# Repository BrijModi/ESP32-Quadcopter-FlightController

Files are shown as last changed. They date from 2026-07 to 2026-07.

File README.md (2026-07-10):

# ESP32-Quadcopter-FlightController

Open-source ESP32-based flight controller for quadcopters, featuring sensor fusion, nested PID control, motor mixing, real-time Wi-Fi PID tuning, and a custom KiCad PCB with support for GPS and FPV modules.

---

## 📘 Introduction
This project is a fully custom **ESP32-based quadcopter flight controller**, built from scratch to provide complete hardware and firmware flexibility.  
Unlike commercial closed-source flight controllers, this system allows direct modification of IMU handling, PID algorithms, motor mixing, and communication layers—making it ideal for learning, research, and UAV experimentation.

The controller runs an **83 Hz control loop**, uses a **complementary filter** for real-time roll/pitch estimation, and stabilizes the quadcopter using **nested PID loops** (Angle + Rate).  
A built-in **Wi-Fi interface** enables on-the-fly PID tuning and telemetry, eliminating the need to reflash firmware between adjustments.

This repository includes the complete firmware, custom KiCad PCB design, calibration and testing utilities, project media, and a comprehensive technical report documenting the system design and implementation.

---

## ⭐ Highlights
- Custom ESP32-based flight controller firmware  
- Complementary filter for attitude estimation  
- Dual-loop PID control for roll, pitch, and yaw  
- Motor mixing for X-configuration quadcopters  
- Real-time Wi-Fi tuning dashboard  
- Custom two-layer PCB with expansion support  
- Stable and tested flight performance (90–95%)  
- Open-source and fully modifiable

---

## 🖼 Drone Image

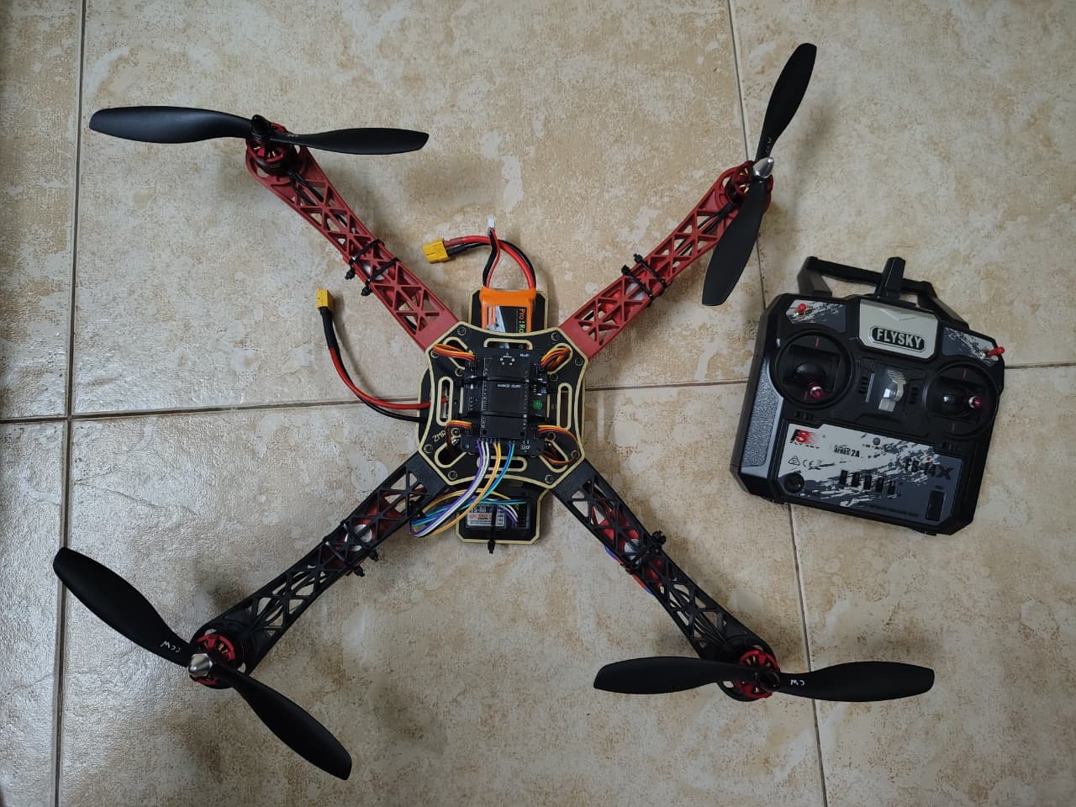
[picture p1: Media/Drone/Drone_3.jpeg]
Custom ESP32 Quadcopter


---

## 🔧 Features
- Real-time IMU data acquisition using MPU6050  
- Complementary filter–based angle estimation  
- Nested PID loops for angle and rate stabilization  
- PWM signal generation for ESCs  
- i-BUS / PWM receiver input handling  
- Wi-Fi HTTP server for dashboard + tuning  
- Support for barometer (alt-hold), GPS, and FPV modules  
- Modular code structure for easy experimentation

---

## 🛠 Hardware Used
- ESP32 DevKit V1
- MPU6050 IMU  
- RS-2212 920KV motors + 30A ESCs  
- FlySky FS-i4X receiver  
- 3S Li-Po battery  
- F450 frame  
- Custom-designed flight controller PCB

---

## 📂 Repository Contents

- `Firmware/`
  - `Main_Firmware/` – Main ESP32-based quadcopter flight controller firmware
  - `Testing_Calibration/` – Calibration, testing, and Wi-Fi PID tuning utilities
  
- `Hardware/`
  - `Drone Flight Controller/` – Complete KiCad project (schematic, PCB layout, and project files)
  - `FC Gerber.zip` – PCB manufacturing (Gerber) files
  - `PCB View.pdf` – PCB layout overview
  - `Schematic.pdf` – Flight controller circuit schematic
  
- `Media/`
  - `Drone/` – Drone assembly, flight controller, and hardware images
  - `Test Flight and Calibration/` – Flight test videos, calibration recordings, and PID response graph

- `Technical Report.pdf` – Comprehensive technical documentation covering hardware design, firmware architecture, implementation, and testing

---

## 💻 Software Requirements

- Arduino IDE 2.x
- ESP32 Arduino Core
- KiCad 9.x (for PCB design)

---

## 📚 Libraries Used

- `Wire` – I²C communication
- `ESP32Servo` – ESC PWM control
- `WiFi` – Wireless communication
- `AsyncTCP` – Asynchronous TCP networking
- `ESPAsyncWebServer` – Web-based PID tuning dashboard
- `SPIFFS` – Web dashboard file storage

---

## 🚀 Getting Started

Follow the steps below to configure and fly the quadcopter for the first time.

### 1. Hardware Setup
- Assemble the quadcopter and connect all hardware components.
- Wire the ESP32, MPU6050, ESCs, receiver, and motors according to the provided schematic.

### 2. Verify Receiver and ESCs
- Upload the firmware from `Firmware/Testing_Calibration/Receiver_PWM_Testing/` to verify proper receiver operation.
- Upload the firmware from `Firmware/Testing_Calibration/ESC_Calibration/` and calibrate all ESCs.

### 3. Calibrate the IMU
- Upload the firmware from `Firmware/Testing_Calibration/IMU_Calibration/`.
- Place the quadcopter on a level surface and perform the IMU calibration.
- Copy the generated accelerometer and gyroscope offset values into both the main flight controller firmware and the PID tuning firmware.

### 4. Tune the PID Controller
- Upload the firmware from `Firmware/Testing_Calibration/PID_Tuning_Webserver/`.
- Connect to the ESP32 Wi-Fi access point and open the PID tuning dashboard.
- Tune the roll, pitch, and yaw PID gains until stable flight performance is achieved.
- Copy the optimized PID values into the main flight controller firmware.

### 5. Upload the Main Flight Controller Firmware
- Open `Firmware/Main_Firmware/Flight_Controller_v2/Flight_Controller_v2.ino`.
- Update the firmware with the calibrated IMU offsets and tuned PID gains.
- Upload the firmware to the ESP32.

### 6. Perform Flight Testing
- Verify the motor rotation direction and propeller orientation.
- Perform an initial low-throttle hover test in a safe, open area.
- Fine-tune the PID gains as required to achieve stable and responsive flight.

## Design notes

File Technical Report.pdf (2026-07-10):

# Design and Implementation of a Custom ESP32-Based Quadcopter Flight Controller

Brij Modi

October 2025

Abstract
This report summarizes the design and implementation of a fully custom-built quadcopter with a self-developed flight controller using an ESP32 microcontroller and an MPU6050 IMU. The main goal is to develop a low-cost, modular, and customizable flight control system that allows total hardware and software flexibility, as opposed to conventional commercial controllers. The system includes real-time attitude estimation by using a complementary filter and stabilization using a dual-loop PID control architecture over roll, pitch, and yaw axes. A web-based Wi-Fi interface for wireless PID tuning without firmware reprogramming allows easy calibration. A quadcopter built using an F450 frame with A2212-1400KV motors, SimonK 30A ESCs, and an FS-i4X transmitter showed stable flights with more than 90% stability in manual flight tests. Other optional functions like altitude hold, GPS navigation support, and FPV camera are integrated into the PCB design for potential autonomous functions and broader application scenarios.

## 1 Introduction

Unmanned Aerial Vehicles (UAVs) have revolutionized various activities such as aerial mapping, surveillance applications, precision agriculture, and scientific exploration. Among the several types of UAVs, quadcopters are renowned for mechanical simplicity, vertical takeoff and landing capabilities, and high maneuverability. Because of this, they are preferred platforms not only in research but also in practical applications.

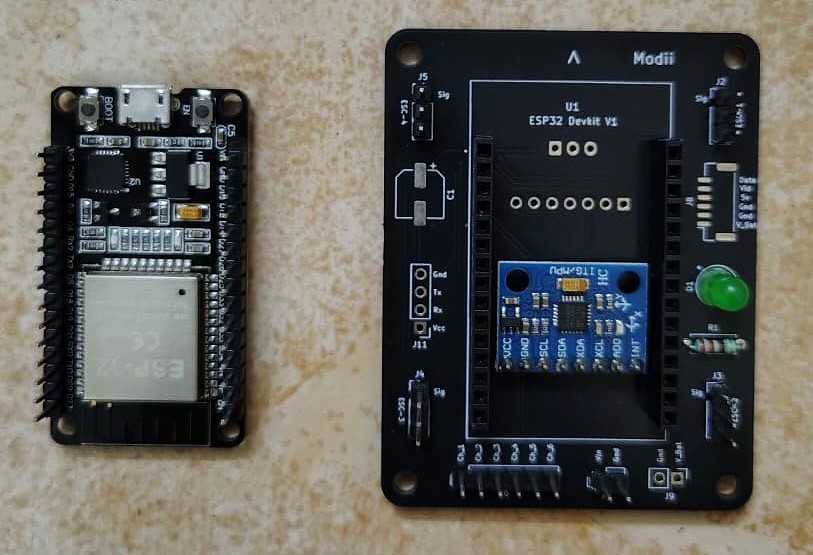
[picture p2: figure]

ESP32-based flight controller PCB.

While commercial flight controllers, such as the KK and Naze32, are very powerful and feature-rich, their closed-source firmware or limited customization usually restricts new control algorithm or sensor configuration experimentation. This limits the educational and research efforts that need deeper insight into embedded control design and firmware customization.
The following work will fill this gap by detailing the design and implementation of a completely custom ESP32-based quadcopter flight controller. It is fitted with an MPU6050 IMU for real-time attitude sensing, a dual-loop PID control structure for precise stabilization, and a web-based interface for wireless tuning. While stable flights can be realized in this project, it focuses more on the end-toend development from circuit design, PCB fabrication to control firmware implementation, thus offering grounds for open, modular UAV research platforms. Optional enhancement features included in the new PCB version of the flight controller are barometer-based altitude hold, GPS navigation support, and an FPV camera interface. These extend basic stabilization functionalities towards making the platform applicable to semi-autonomous and research-oriented UAV development.

## 2 System Overview

### 2.1 Overall System Description

The custom-built quadcopter consists of integrated hardware and software subsystems working together to maintain stable flight and respond to pilot commands. The core modules include:

- Sensing: MPU6050 IMU provides acceleration and angular rate data.
- Computation: ESP32 microcontroller executes sensor fusion and PID control.
- Actuation: Four brushless DC motors driven by ESCs generate thrust and torque.
- Communication: Wi-Fi and RC receiver enable wireless control and tuning.

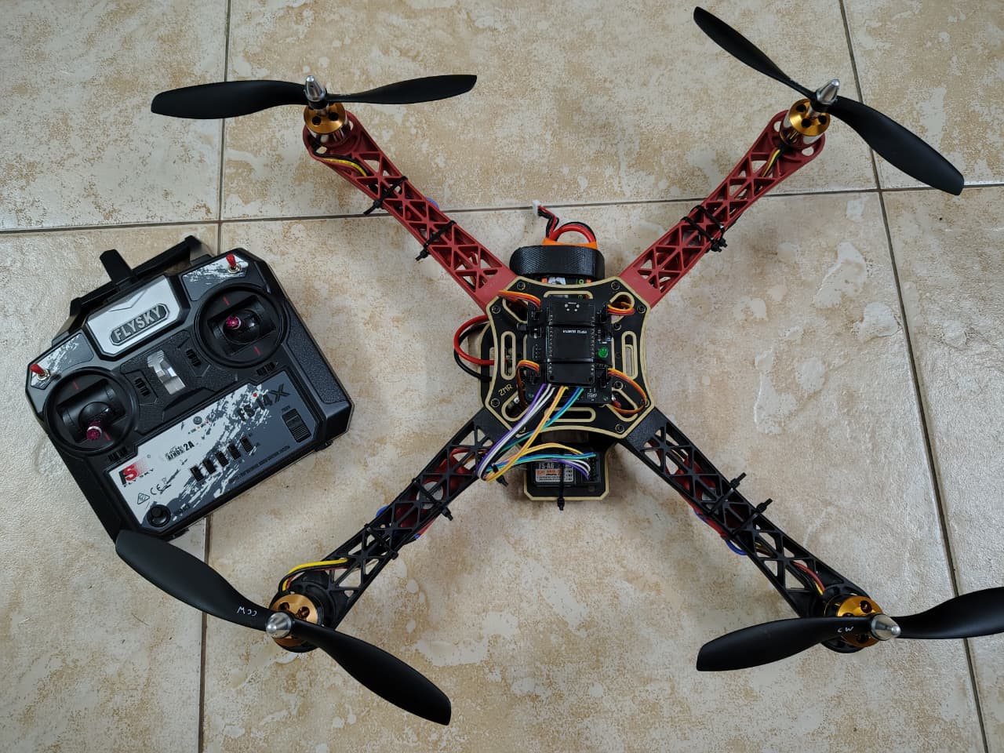
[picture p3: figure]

Figure 1: Custom-built quadcopter with ESP32-based flight controller.

### 2.2 Functional Architecture

The flight controller is a closed-loop system constantly processing sensor data, computing corrective actions, and adjusting motor speeds. Figure 2 depicts the functional architecture with the ESP32 acting as the central processing node.

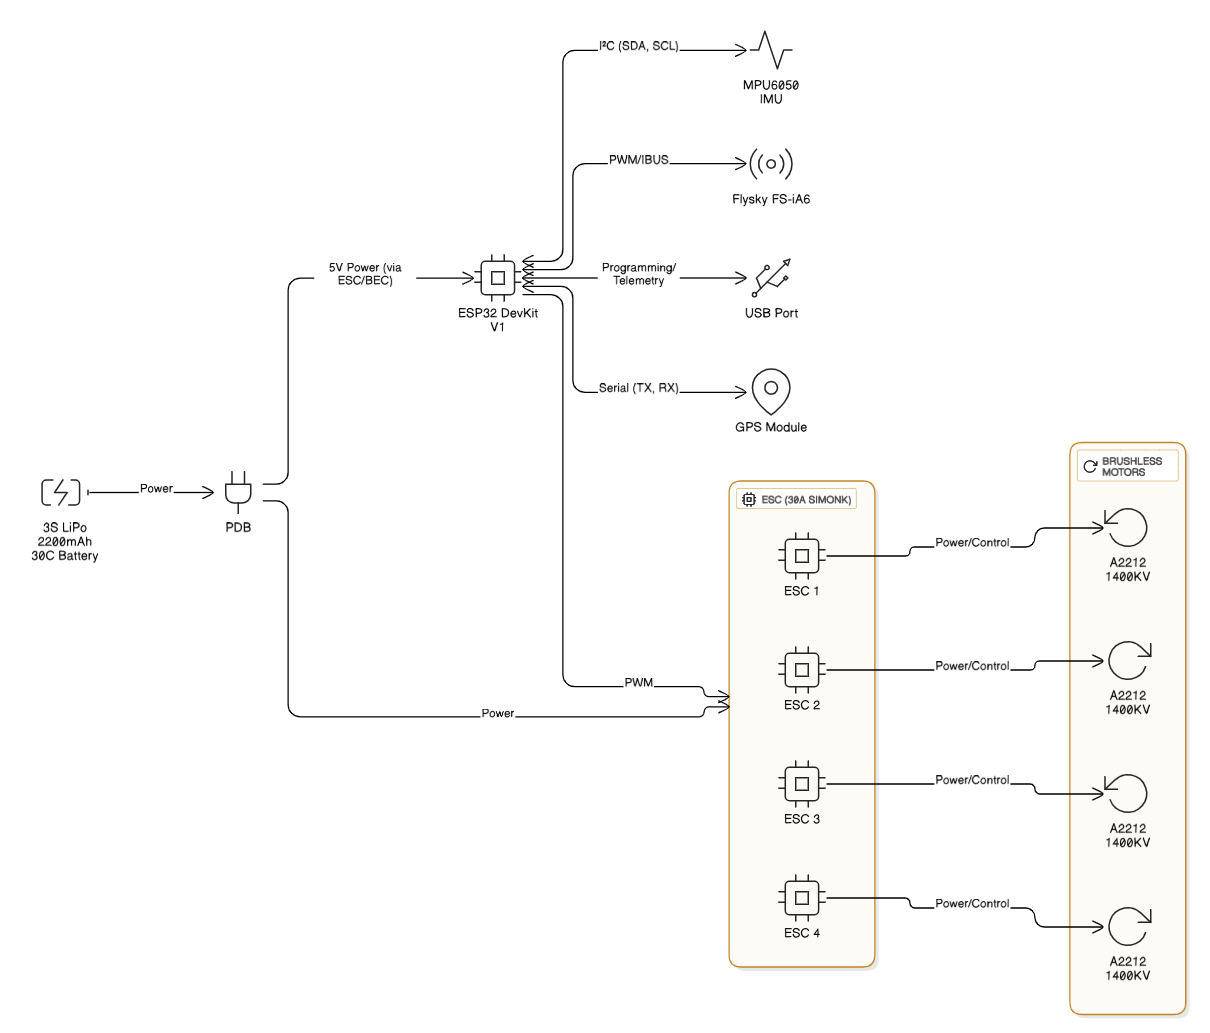
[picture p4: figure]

Figure 2: Functional block diagram of the flight control system.

### 2.3 Sensor Fusion and Communication

Accurate attitude estimation is achieved using a complementary filter that fuses accelerometer and gyroscope data from the MPU6050. Communication between modules is handled through:
- I
2C for IMU communication,
- PWM / i-BUS for RC inputs,
- PWM outputs for ESCs,
- Wi-Fi (HTTP) for telemetry and PID tuning.

### 2.4 Flight Control Data Flow

The flight controller firmware acts as a continuous closed-loop system that translates sensor data and inputs from the pilot to corresponding precise outputs in motor control. Figure 3 shows the complete flow from initialization to the continuation of the loop. Every element has a specific job in this real-time control architecture to provide stable and agile flight.

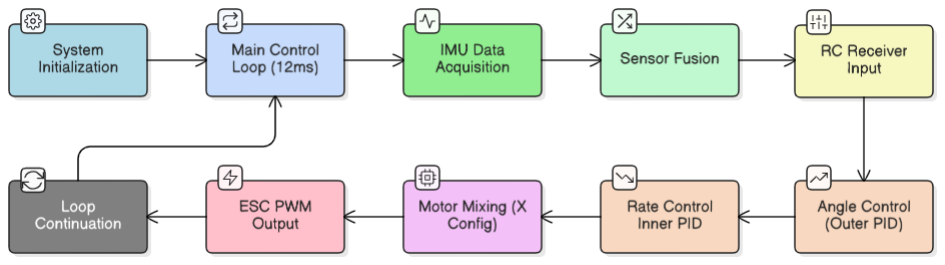
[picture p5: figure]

Figure 3: Data flow diagram of the ESP32-based flight control loop.

The process can be divided into ten main stages:

1. System Initialization: Initializes the IMU, receiver interrupts, and ESC interfaces. All sensors are calibrated, and timing for the 12 ms control loop is configured.
2. Main Control Loop (12 ms): This loop runs continuously at a frequency of approximately 83 Hz, maintaining real-time flight control. Each iteration performs sensing, estimation, control computation, and actuation.
3. IMU Data Acquisition: Reads accelerometer and gyroscope data via the I²C interface and computes initial roll and pitch angles.
4. Sensor Fusion: Combines gyro and accelerometer data using a complementary filter to obtain stable, drift-free filtered roll and pitch angles.
5. RC Receiver Input: The receiver provides six PWM channels representing pilot inputs—throttle, roll, pitch, yaw, and auxiliary controls. These PWM signals are converted into normalized control values in the firmware to derive the desired attitude and throttle commands.
6. Angle Control (Outer PID): This calculates the error between the desired and measured angles; the output of the PID is the target angular rate for roll and pitch correction.
7. Rate Control (Inner PID): It controls the angular velocity about each axis based on the rate errors to achieve control signals for roll, pitch, and yaw stabilization.
8. Motor Mixing (X-Config): The control signals from the PID loops are combined according to the quadcopter’s X-frame geometry. It determines how much each of the four motors contributes to provide roll, pitch, yaw, and throttle commands to ensure well-balanced thrust and torque.
9. ESC PWM Output: Converts motor commands into 1000–2000 µs PWM signals and sends them to the ESCs for motor speed control.
10. Loop Continuation: Repeats the entire process every 12 ms for continuous feedback and real-time stabilization.

From a control viewpoint, this is a hierarchical feedback structure where the outer loop controls attitude (angle), and the inner one is responsible for angular rate control. This dual PID approach improves stability and responsiveness. Moreover, by fusing sensor data and accurately mixing motor power, the flight performance is dependable, equal or superior to that of commercial implementations.

## 3 Hardware Design

### 3.1 Circuit Design and Integration

The ESP32 serves as the central processor, interfacing with the MPU6050 via I
textsuperscript2C and the RC receiver via PWM/i-BUS. Four PWM outputs are used to drive the ESCs, which in turn drive the brushless DC motors. A 5V regulator ensures a stable voltage supply to the logic circuits.

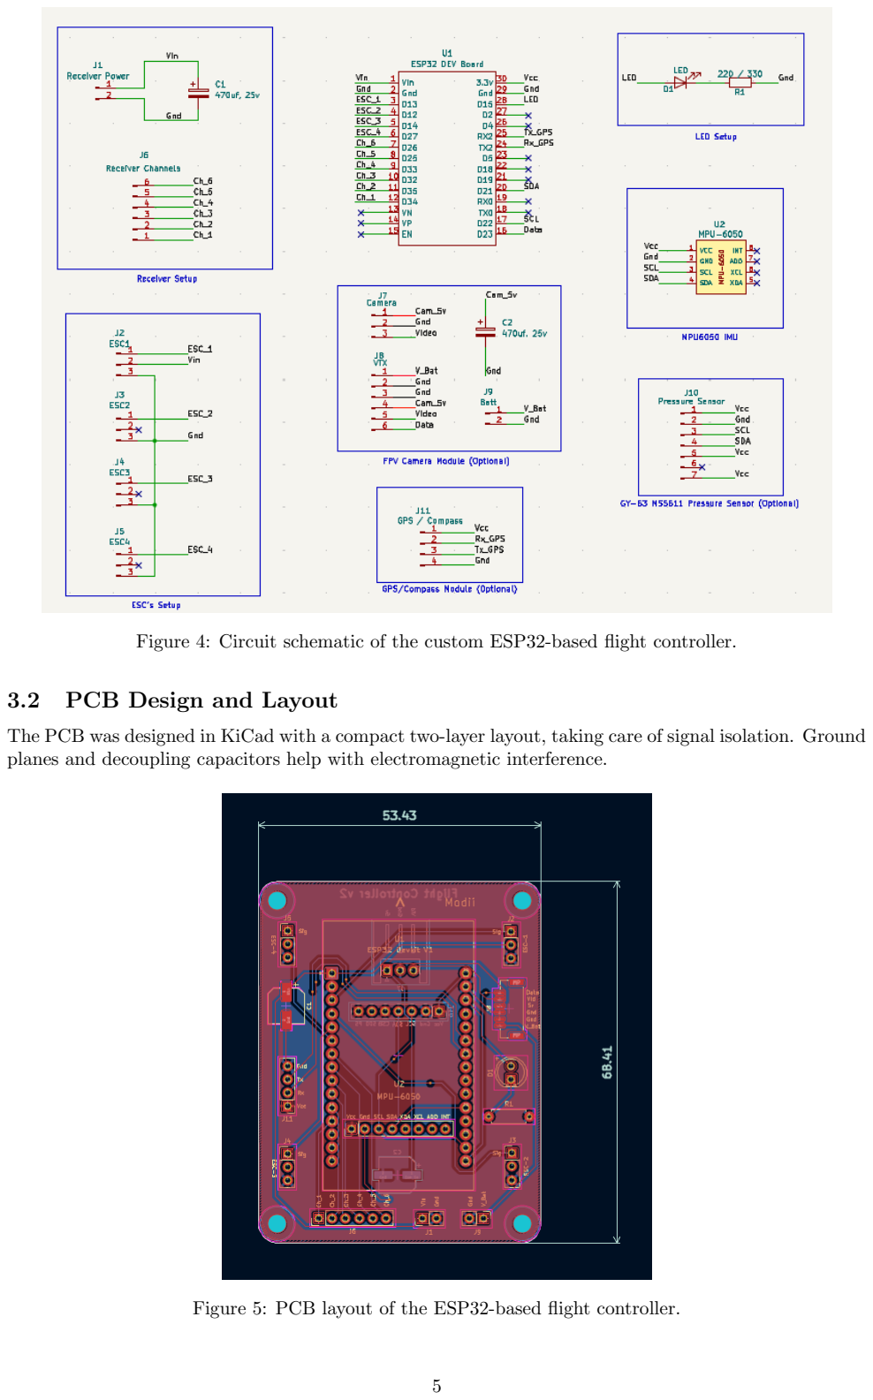
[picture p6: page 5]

Figure 4: Circuit schematic of the custom ESP32-based flight controller.

### 3.2 PCB Design and Layout

The PCB was designed in KiCad with a compact two-layer layout, taking care of signal isolation. Ground planes and decoupling capacitors help with electromagnetic interference.

Figure 5: PCB layout of the ESP32-based flight controller.

### 3.3 Component Selection and Justification

Table 1: Major hardware components used in the quadcopter.

Component | Specification | Function
ESP32 Dev Module | Dual-core MCU, Wi-Fi/BLE | Main flight controller
MPU6050 IMU | 3-axis accelerometer + gyroscope | Attitude sensing
Barometer (Optional) | GY-63 MS5611 | Enables altitude hold functionality
GPS Module (Optional) | NEO-6M | Provides position data for autonomous navigation
A2212 BLDC Motor | 1400 KV | Propulsion
ESC | 30A, SimonK firmware | Motor control
FlySky FS-i4X Receiver | 4-channel, 2.4 GHz | Pilot input
Li-Po Battery | 11.1V, 2200 mAh, 30C | Power source
F450 Frame | 450 mm diagonal, plastic/fiber | Drone structure

### 3.4 Mechanical and Frame Design

The ideal balance of strength and weight is achieved in the F450 frame. The span between the motor mounts in this frame is 450 mm, where the diagonal distance from motor to motor is 45 cm. The approximate weight of the drone was 1.25 kg. Its design guarantees a low center of gravity, even weight distribution, and an optimal thrust-to-weight ratio of about 2:1 for stable flights. Besides, the flight controller was installed at the geometric center of the frame to minimize the rotational inertia and improve attitude stability. The MPU6050 IMU was installed on vibration-isolating foam to damp highfrequency motor and propeller vibrations, thus enhancing the accuracy of angle estimation. Due to the symmetric X-configured F450 frame, the roll and pitch responses were uniform, which reduced complexity in the calculation of motor mixing and improved overall flight performance.

### 3.5 Power Distribution and Safety

Power is supplied by a 3S Li-Po battery through a PDB. ESCs are powered directly with 11.1V; the ESP32 and IMU each receive their power from a 5V regulator. Electrical noise is reduced by adding capacitors, while proper grounding minimizes interference between digital and power circuits.

## 4 Software Architecture

### 4.1 Firmware Structure

The firmware is modular, with separate tasks for sensing, control, and communication. Each control loop (executed every 12 ms) performs the following:

1. Acquire IMU data.
2. Compute attitude using a complementary filter.
3. Read pilot inputs from RC receiver.
4. Run nested PID control loops.
5. Update ESC PWM signals.
6. Send real-time telemetry via Wi-Fi.

### 4.2 Complementary Filter

θroll,est(k) = 0.991[θroll,est(k − 1) + ωgyro,rollt] + 0.009θacc,roll | (1)
θpitch,est(k) = 0.991[θpitch,est(k − 1) + ωgyro,pitcht] + 0.009θacc,pitch | (2)

with t = 0.012 s. This filter minimizes gyro drift while preserving responsiveness.

### 4.3 Control Flow (Dual PID Loops and Yaw)

Roll and pitch stabilization are achieved using a dual PID loop—an outer loop for angle control and an inner loop for angular rate control. Yaw uses a single rate PID.

Outer Loop – Angle PID

eangle[k] = Desired Angle − Measured Angle | (3)

uangle[k] = Kpa

eangle[k] + Kia

Xeangle + Kda

∆eangle
t

(4)

Inner Loop – Rate PID

erate[k] = Desired Rate − Measured Rate | (5)

urate[k] = Kpr

erate[k] + Kir

Xerate + Kdr

∆erate
t

(6)

### 4.4 PID Control Algorithm

The general PID control law:

u[k] = Kpe[k] + Ki

Xe[k] + Kd

de
dt | (7)

## 5 Testing and Results

### 5.1 Flight Test Procedure

Flight tests were carried out in open-ground conditions under low wind. Tests included hover stability, roll/pitch step responses, and yaw hold performance. PID gains were adjusted wirelessly via Wi-Fi interface.

### 5.2 Performance Evaluation

- Hover achieved at 40–50% throttle.
- Roll/pitch error maintained within ±2
◦
- Battery endurance: 10–15 minutes.
- 90-95% overall flight stability observed.

### 5.3 PID Tuning Results

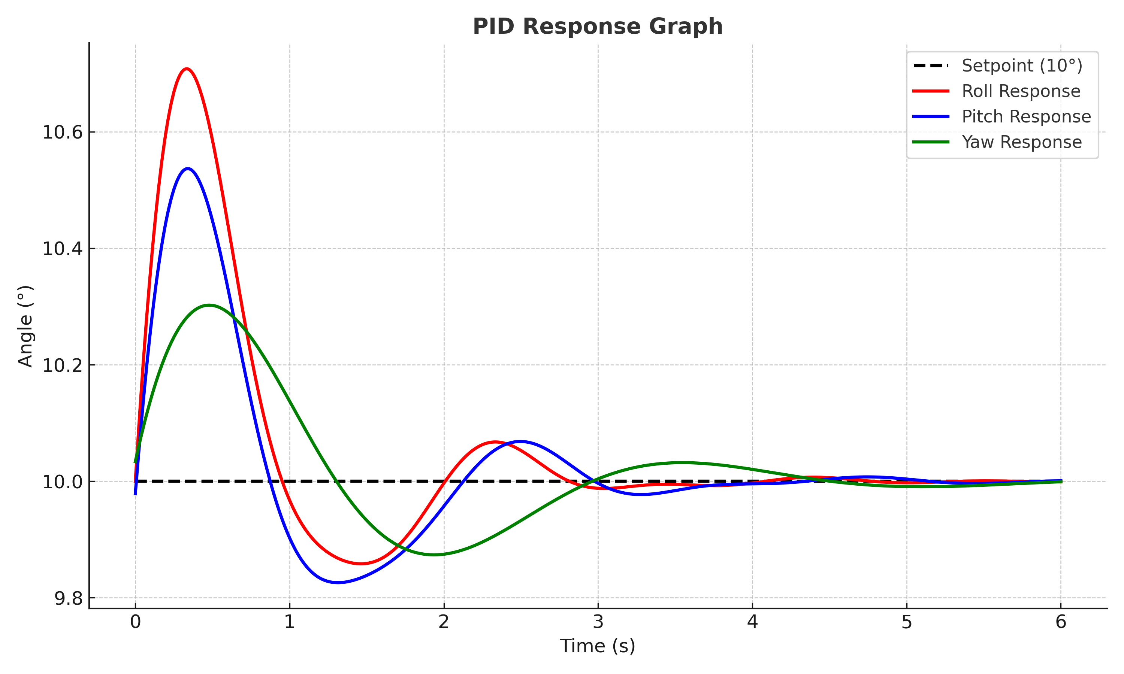
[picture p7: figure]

Figure 6: PID tuning response.

### 5.4 PID Tuning Parameters

During the flight testing phase, PID gains were tuned iteratively through the wireless web interface to achieve smooth and stable flight behavior. Table 2 lists the final optimized gains for roll, pitch, and yaw axes. Identical gains were used for roll and pitch due to the symmetric quadcopter geometry.

Table 2: Final tuned PID gains providing stable flight performance.

Control Loop | Axis | KP | KI | KD
Angle (Outer Loop) | Roll | 3.6 | 0.01 | 0.03
Angle (Outer Loop) | Pitch | 3.6 | 0.01 | 0.03
Rate (Inner Loop) | Roll | 1.25 | 0.02 | 0.0086
Rate (Inner Loop) | Pitch | 1.25 | 0.02 | 0.0086
Rate (Inner Loop) | Yaw | 3.8 | 3.00 | 0.02

These parameters offered balanced responsiveness and damping, minimizing overshoot and ensuring reliable hover and attitude stability across test flights.

### 5.5 Observations and Challenges

- Sensitivity to IMU calibration: Small changes in either temperature or mounting orientation affected initial bias values, so multiple test flights were preceded by recalibrations.
- Initial PID tuning resulted in overshoot and oscillations, which were reduced through iterative tunings using the wireless interface.
- ESC signal consistency: Several of the ESCs showed some variation in response time; this made the motor outputs uneven until proper min–max calibration was performed.
- Optimizations in loop timing were required to maintain a constant 12 ms control cycle for reliable performance of the PID.

## 6 Applications and Future Scope

- Autonomous Navigation Experiments: Provides the baseline for testing GPS-based waypoint navigation and altitude hold modes together with autonomous take-off/landing routines.
- Aerial Surveillance and Monitoring: Can be adapted for lightweight surveillance applications by integrating an FPV camera or low-latency video transmission system.
- Precision Agriculture: Capable of carrying small sensors or cameras that could monitor crop health, soil patterns, or the performance of field mapping tasks.
- Prototype Development for Custom UAVs: Offers a flexible flight-control core to assist in building specialized drones, whether they are inspection drones, mapping platforms, or indoor research UAVs.

## 7 Conclusion

This custom ESP32-based flight controller prototype demonstrates that a low-cost microcontroller, supported by efficient sensor fusion and a twin-loop PID architecture, is capable of reliable quadcopter stabilization, comparable to most commercial systems. It managed to run 10–15 test flights with constant stability of 90–95%, proving the accuracy of the complementary filter, the efficiency of the nested control loops, and the strength of the general hardware–software integration.
The project encompasses all aspects of the design cycle: from circuit development and perfboard prototyping to PCB layout, firmware implementation, and flight testing, thereby showcasing end-toend competency in embedded control systems. Adding optional features such as altitude hold, GPS navigation support, and FPV camera connectivity extends the functionality of the controller even more in its PCB version.
In general, this work showcases a complete, modular, and extensible flight-control platform that will be an excellent starting point for advanced UAV research, including autonomous navigation experiments, and also for any further enhancements, like computer-vision-based control or multi-sensor fusion.

## 8 References

- Espressif Systems, ESP32 Technical Reference Manual, 2023.
- InvenSense Inc., MPU6050 Datasheet.
- Pratik Phadte, Flight Controller Development Tutorials, 2024. Educational video series on IMU handling, PID control, and multirotor stabilization.
- Joop Brokking, DIY Arduino-Based Flight Controller Series, 2015. Technical tutorials covering IMU filtering, PID tuning, and motor–mixing algorithms for quadcopters.
- ˚Astr¨om, K.J., H¨agglund, T., PID Controllers: Theory, Design, and Tuning, 2006.

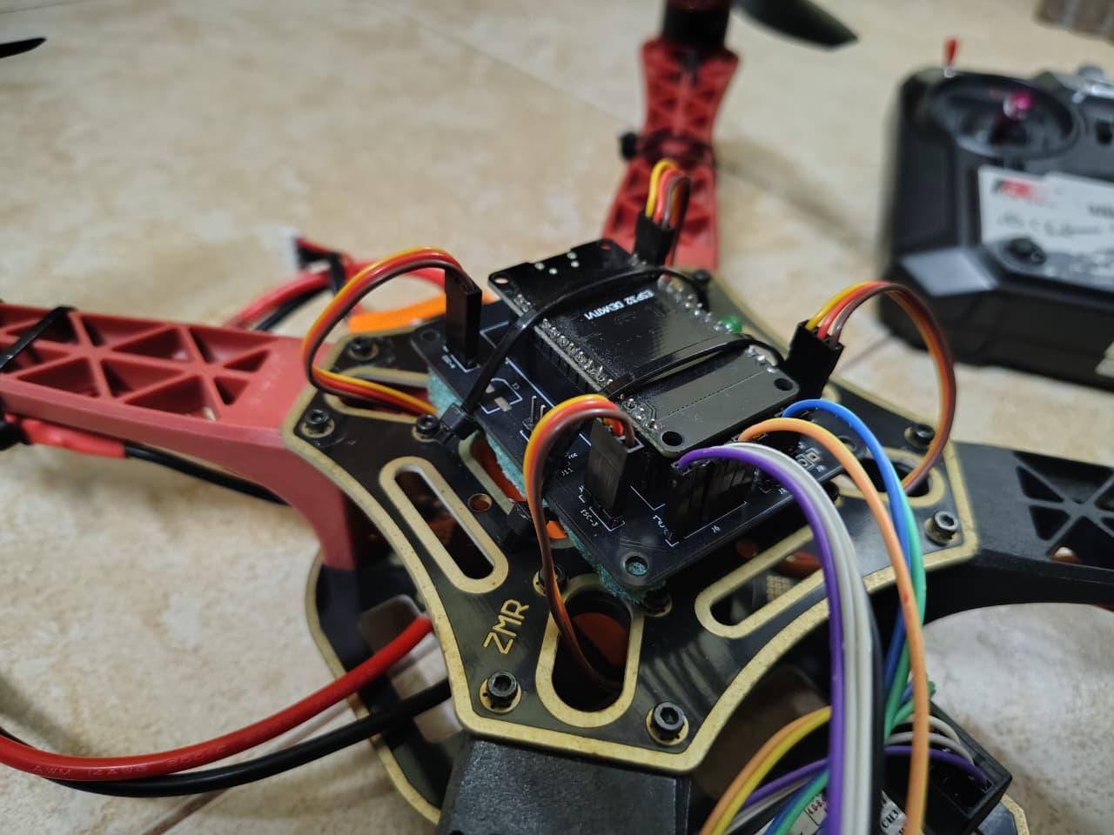
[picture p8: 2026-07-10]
Media/Drone/Drone_4.jpeg

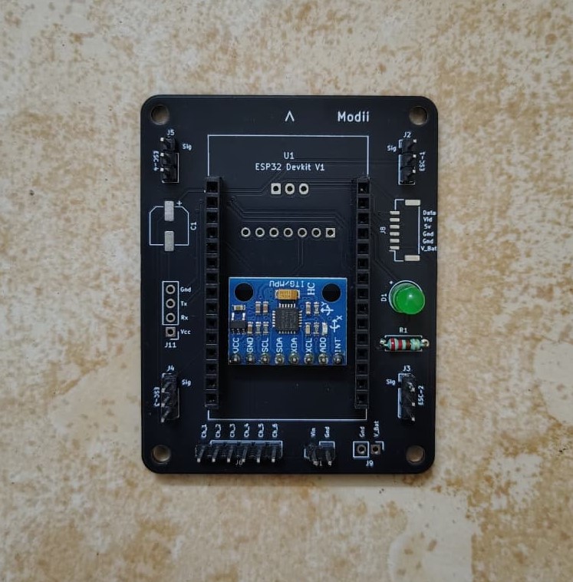
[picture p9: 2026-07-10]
Media/Drone/Flight_Controller_1.jpg

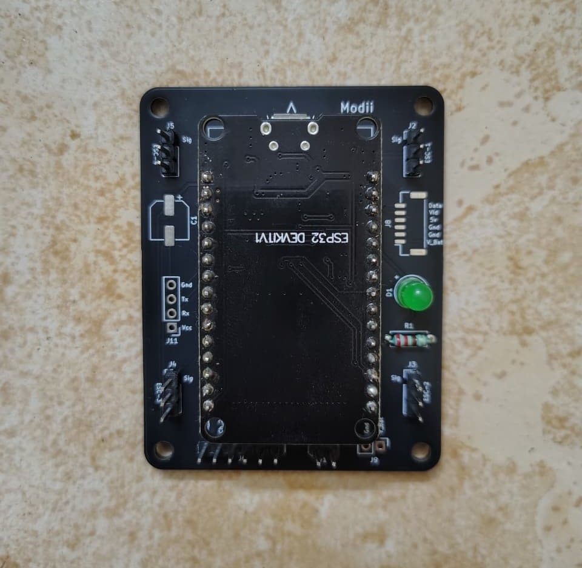
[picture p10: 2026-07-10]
Media/Drone/Flight_Controller_Full.jpg

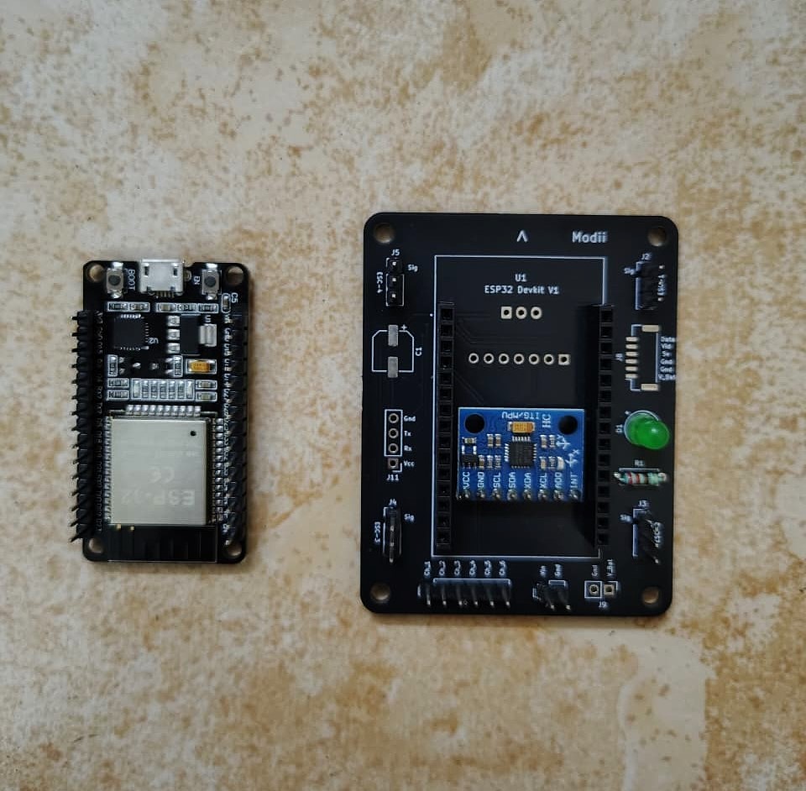
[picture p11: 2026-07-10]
Media/Drone/Flight_Controller.jpg

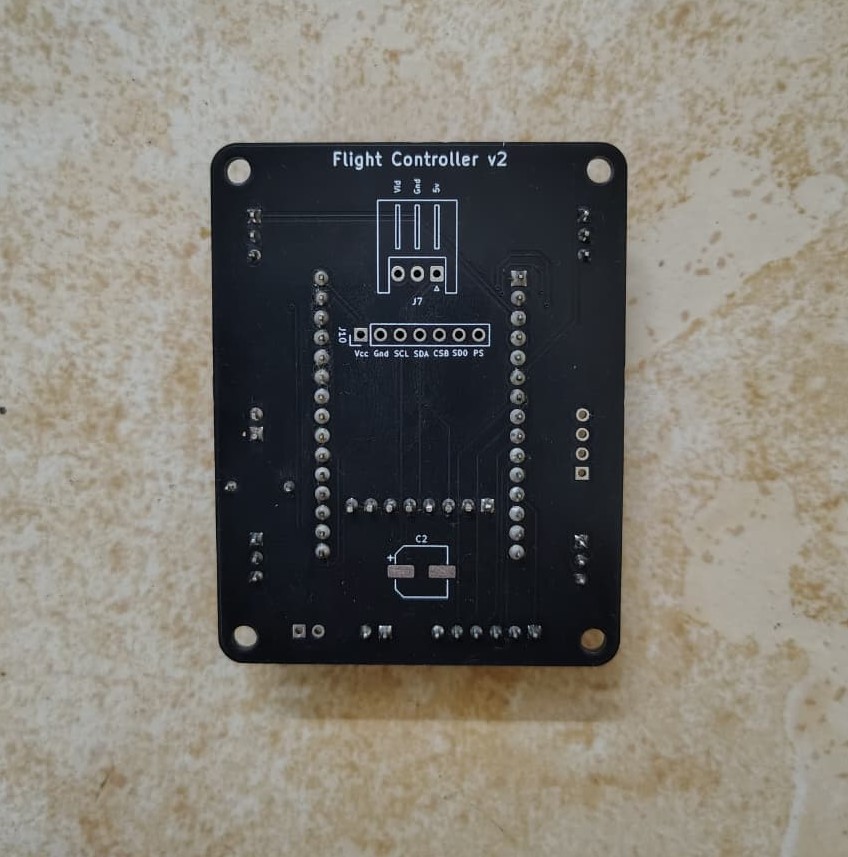
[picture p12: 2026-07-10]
Media/Drone/Flight_Controller_Back.jpg

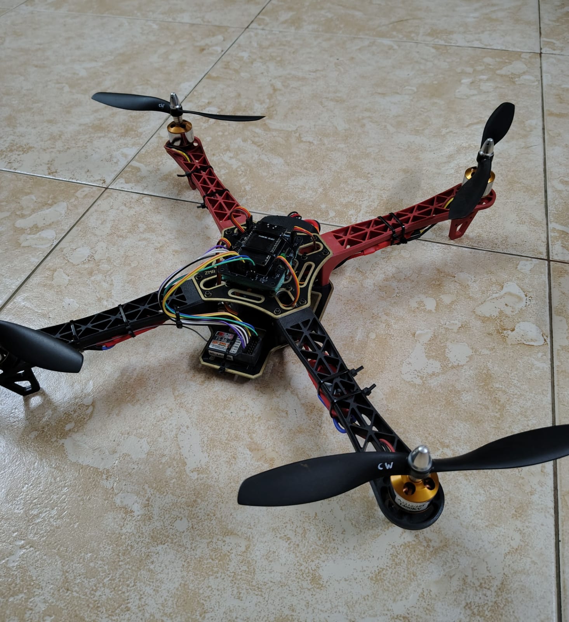
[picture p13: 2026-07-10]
Media/Drone/Drone.jpeg

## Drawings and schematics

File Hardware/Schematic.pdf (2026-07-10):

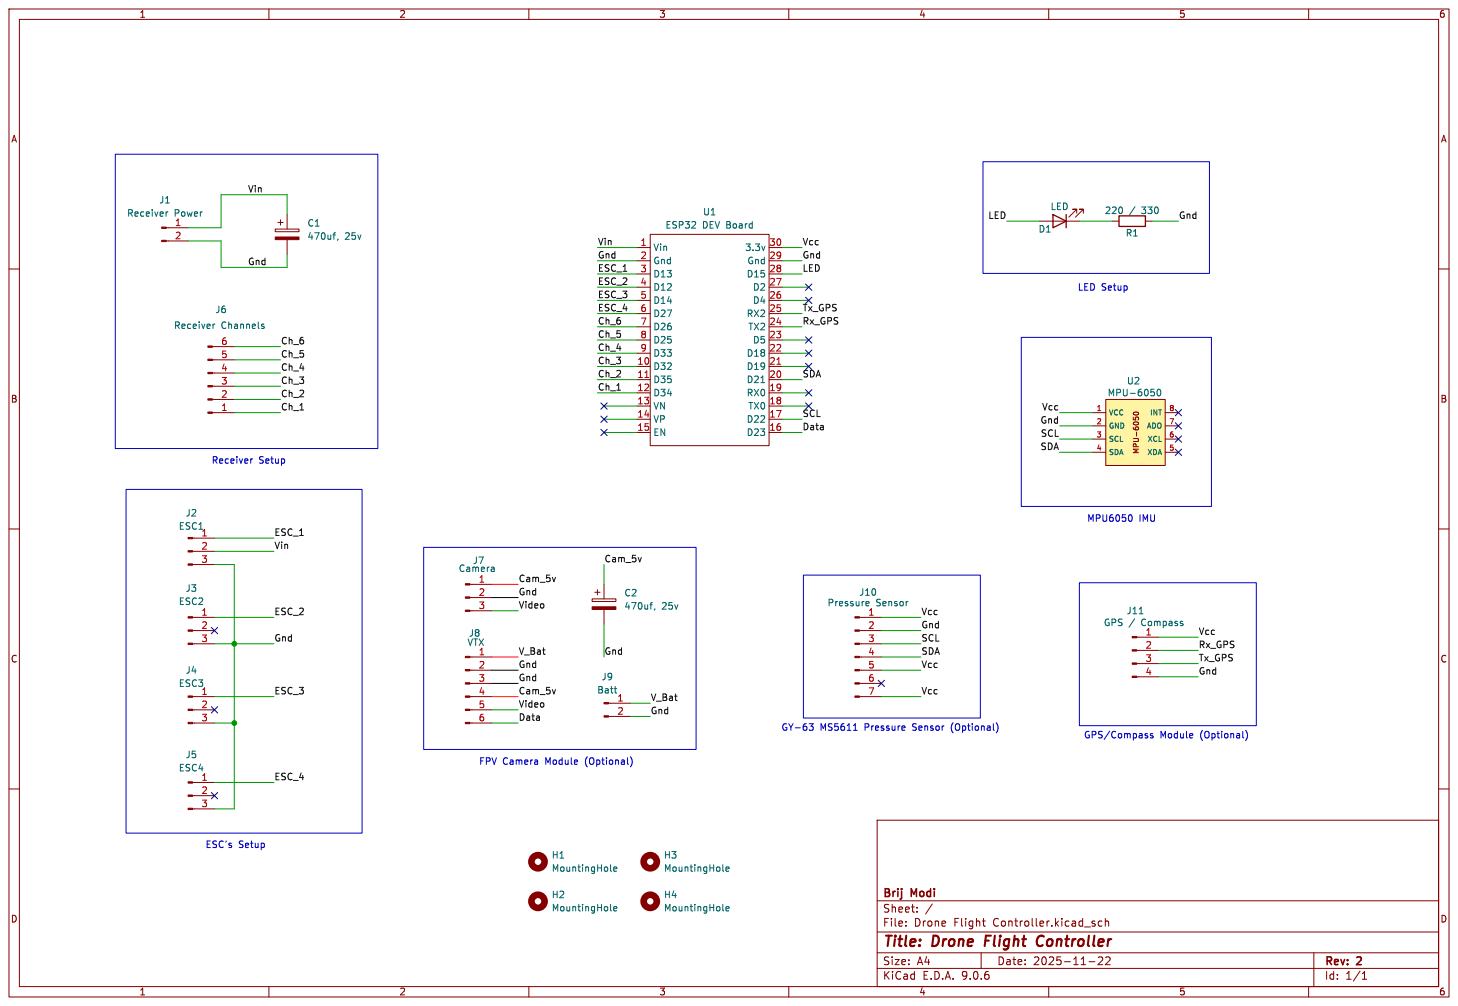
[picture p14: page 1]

LED
LED Setup GY-63 MS5611 Pressure Sensor (Optional)

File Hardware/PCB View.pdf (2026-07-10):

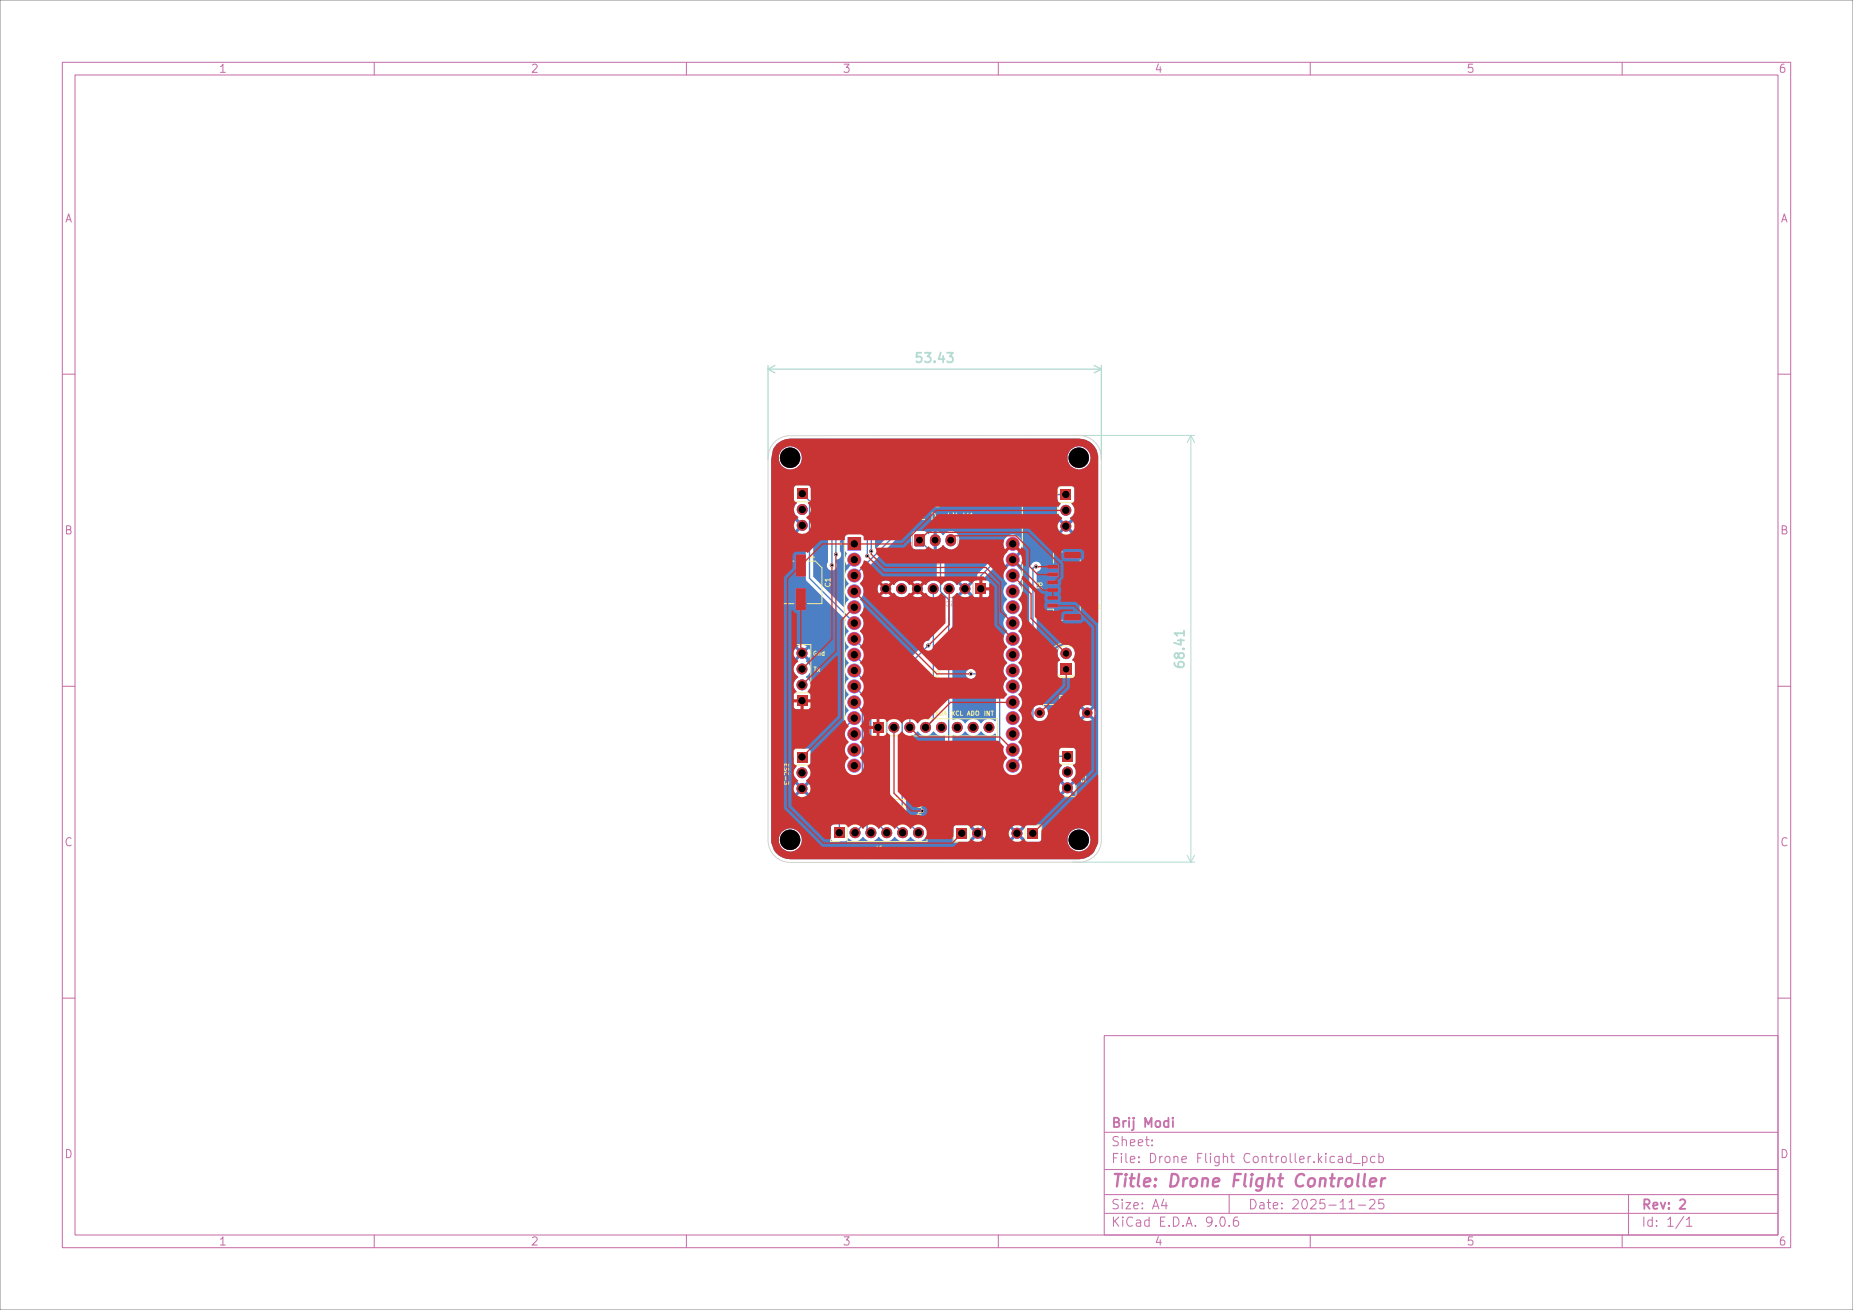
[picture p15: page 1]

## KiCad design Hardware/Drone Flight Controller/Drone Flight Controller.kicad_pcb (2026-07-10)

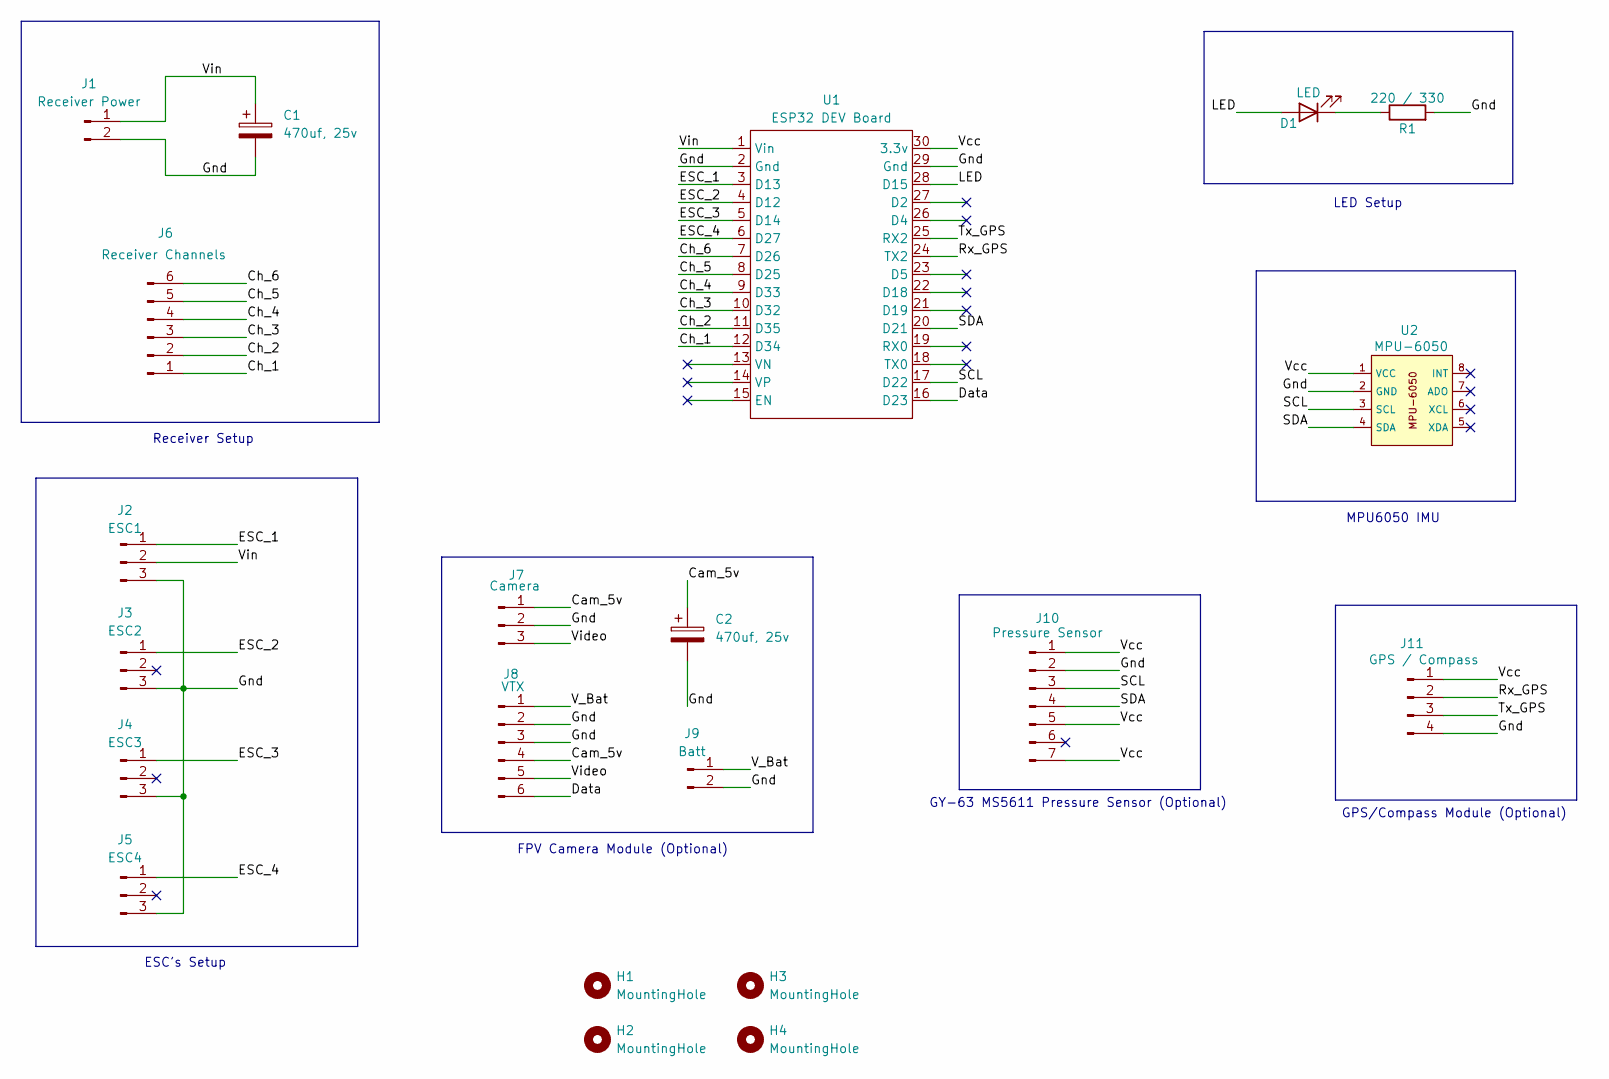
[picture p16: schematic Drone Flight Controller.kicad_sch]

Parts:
C1, C2: 470uf, 25v; CP_Elec_6.3x7.7
D1: LED; LED_D5.0mm
H1, H2, H3, H4: MountingHole; MountingHole_3.2mm_M3
J1: Receiver Power; PinHeader_1x02_P2.54mm_Vertical
J2: ESC1; PinHeader_1x03_P2.54mm_Vertical
J3: ESC2; PinHeader_1x03_P2.54mm_Vertical
J4: ESC3; PinHeader_1x03_P2.54mm_Vertical
J5: ESC4; PinHeader_1x03_P2.54mm_Vertical
J6: Receiver Channels; PinHeader_1x06_P2.54mm_Vertical
J7: Camera; JST_XH_S3B-XH-A_1x03_P2.50mm_Horizontal
J8: VTX; JST_GH_SM06B-GHS-TB_1x06-1MP_P1.25mm_Horizontal
J9: Batt; PinHeader_1x02_P2.54mm_Vertical
J10: Pressure Sensor; PinHeader_1x07_P2.54mm_Vertical
J11: GPS / Compass; PinHeader_1x04_P2.54mm_Vertical
R1: 220 / 330; R_Axial_DIN0207_L6.3mm_D2.5mm_P7.62mm_Horizontal
U1: ESP32 DEV Board; MODULE_ESP32_DEVKIT_V1
U2: MPU-6050; PinHeader_1x08_P2.54mm_Vertical

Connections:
/Cam_5v: C2.1, J7.1, J8.4
/Ch_1: J6.1, U1.12 (D34)
/Ch_2: J6.2, U1.11 (D35)
/Ch_3: J6.3, U1.10 (D32)
/Ch_4: J6.4, U1.9 (D33)
/Ch_5: J6.5, U1.8 (D25)
/Ch_6: J6.6, U1.7 (D26)
/Data: J8.6, U1.16 (D23)
/ESC_1: J2.1, U1.3 (D13)
/ESC_2: J3.1, U1.4 (D12)
/ESC_3: J4.1, U1.5 (D14)
/ESC_4: J5.1, U1.6 (D27)
/Gnd: C1.2, C2.2, J1.2, J2.3, J3.3, J4.3, J5.3, J7.2, J8.2, J8.3, J9.2, J10.2, J11.4, R1.2, U1.2 (Gnd), U1.29 (Gnd), U2.2 (GND)
/LED: D1.2 (A), U1.28 (D15)
/Rx_GPS: J11.2, U1.24 (TX2)
/SCL: J10.3, U1.17 (D22), U2.3 (SCL)
/SDA: J10.4, U1.20 (D21), U2.4 (SDA)
/Tx_GPS: J11.3, U1.25 (RX2)
/V_Bat: J8.1, J9.1
/Vcc: J10.1, J10.5, J10.7, J11.1, U1.30 (3.3v), U2.1 (VCC)
/Video: J7.3, J8.5
/Vin: C1.1, J1.1, J2.2, U1.1 (Vin)
unnamed: D1.1 (K), R1.1

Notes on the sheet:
MPU6050 IMU
LED Setup
FPV Camera Module (Optional)
Receiver Setup
GPS/Compass Module (Optional)
GY-63 MS5611 Pressure Sensor (Optional)
ESC's Setup

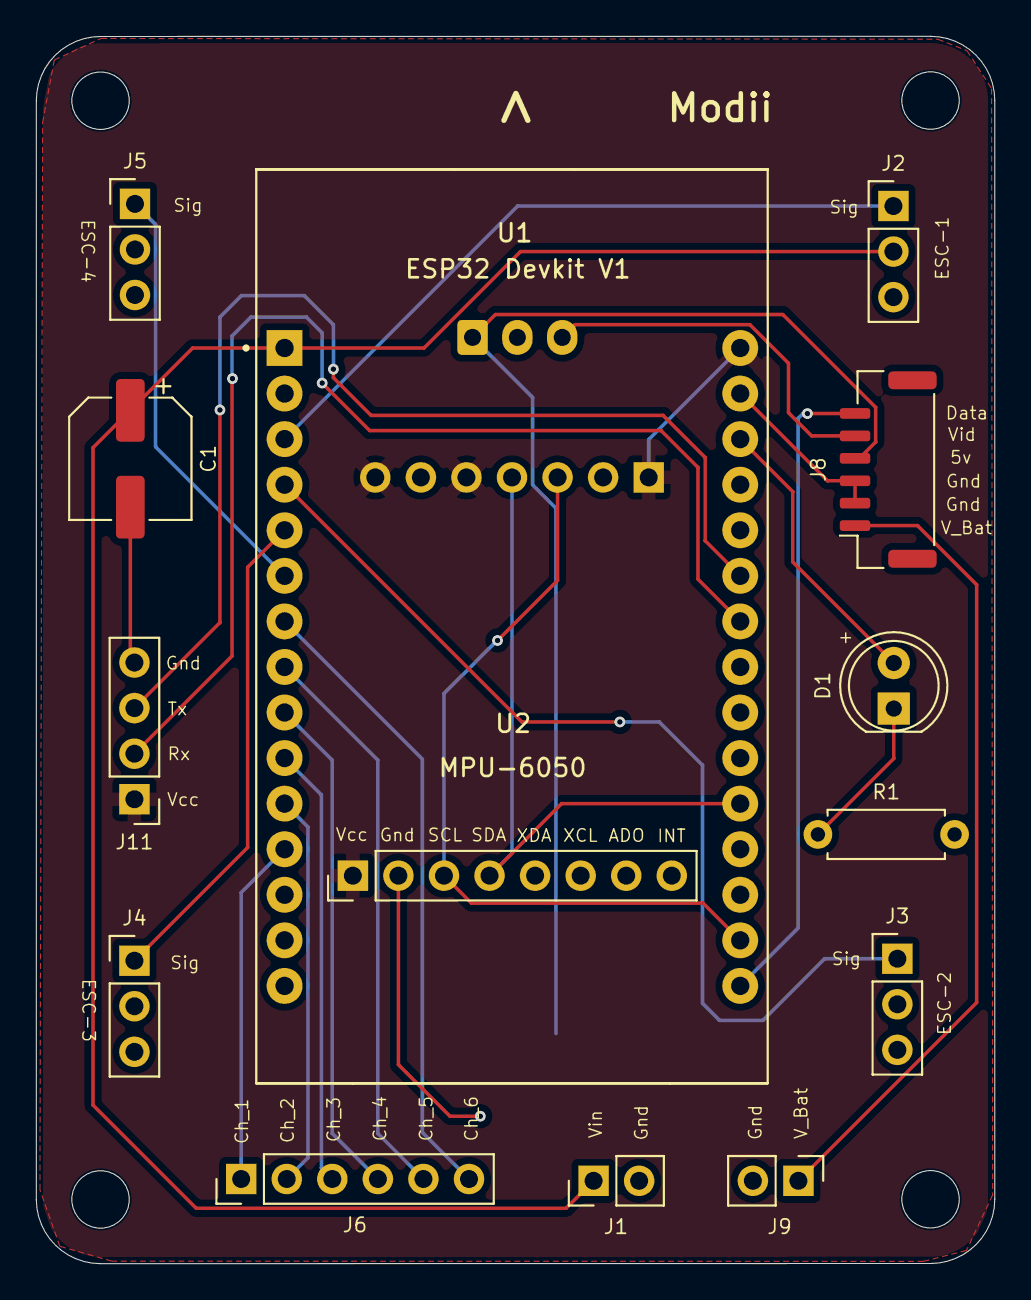
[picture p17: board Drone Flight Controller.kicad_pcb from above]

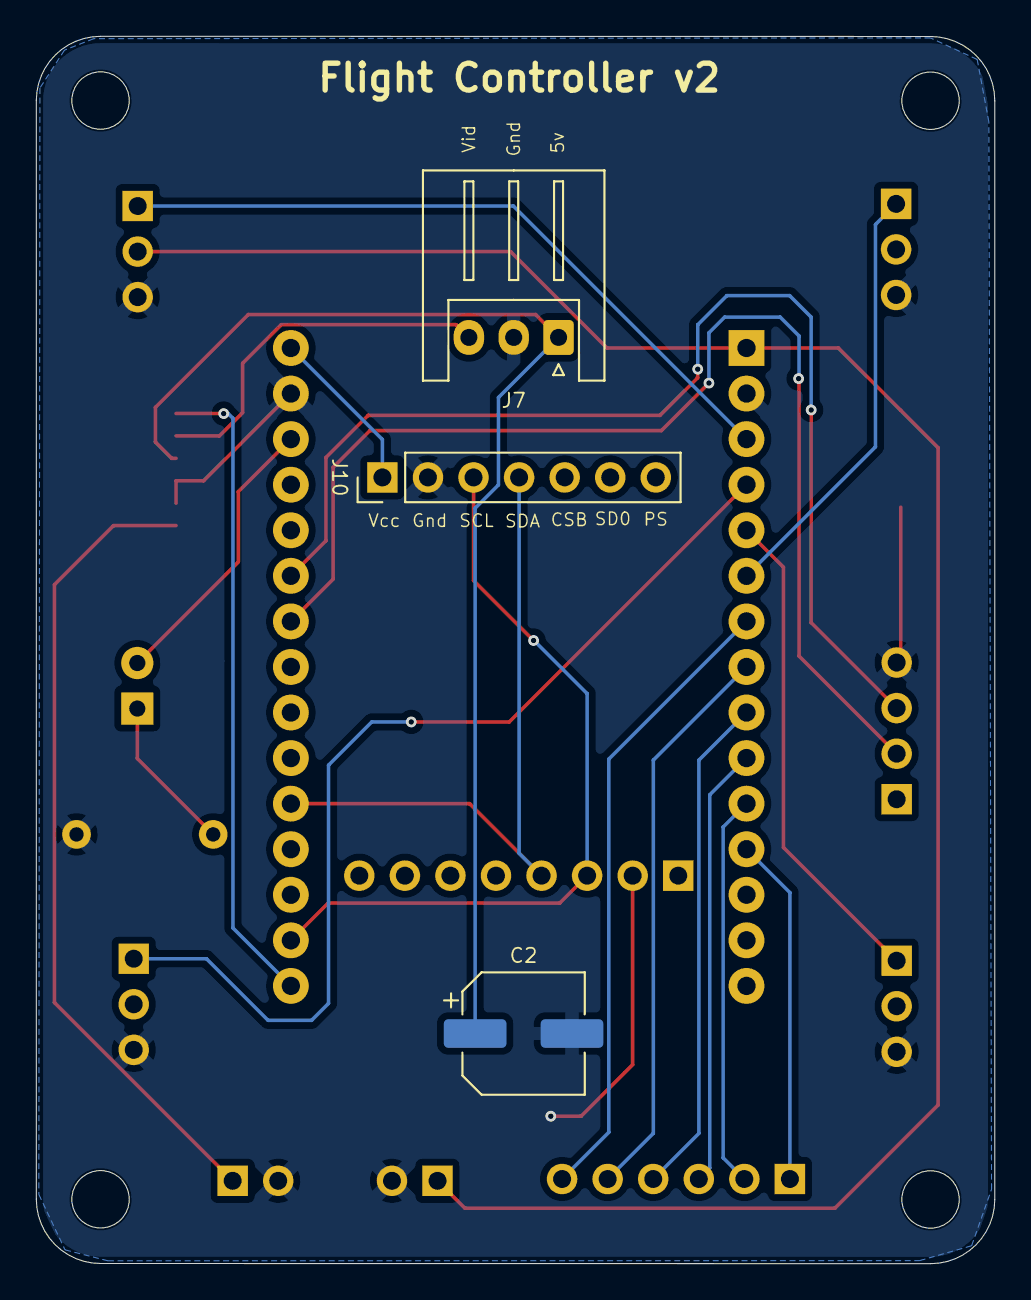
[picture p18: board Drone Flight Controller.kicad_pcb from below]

Board: 2 copper layers, 53.4 x 68.4 mm, 21 parts (3 on the bottom side), 23 nets.

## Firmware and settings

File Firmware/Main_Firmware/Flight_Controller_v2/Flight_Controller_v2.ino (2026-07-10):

#include <Wire.h>
#include <ESP32Servo.h> 

// ---------- Global Variables ---------- //
volatile float RatePitch, RateRoll, RateYaw;
float RateCalibrationPitch, RateCalibrationRoll, RateCalibrationYaw;
float AccXCalibration, AccYCalibration, AccZCalibration;

int ESCfreq = 500; // ESC PWM frequency (Hz)

// ----- PID constants (Angle) ----- //
float PAngleRoll=3.8;
float IAngleRoll=0.021;
float DAngleRoll=0.032;

float PAnglePitch=PAngleRoll;
float IAnglePitch=IAngleRoll;
float DAnglePitch=DAngleRoll;

// ----- PID constants (Rate) ----- //
float PRateRoll = 1.25;
float IRateRoll = 0.021;
float DRateRoll = 0.012;

float PRatePitch = PRateRoll;
float IRatePitch = IRateRoll;
float DRatePitch = DRateRoll;

float PRateYaw = 3;
float IRateYaw = 1.4;
float DRateYaw = 0.015;

uint32_t LoopTimer;
float t = 0.010; 
// t = 0.010 Loop time (≈100Hz)
// t = 0.008 Loop time (~125Hz) or (Faster, more load)
// t = 0.012 Loop time (~83Hz) (Slower, less load)

// ----- Motor setup (X configuration) ----- //
Servo mot1, mot2, mot3, mot4;
// mot1 = FR (CCW), mot2 = RR (CW), mot3 = RL (CCW), mot4 = FL (CW)
const int mot1_pin = 13;
const int mot2_pin = 12;
const int mot3_pin = 14;
const int mot4_pin = 27;

// ----- Receiver setup ----- //
volatile uint32_t current_time;
volatile uint32_t last_channel_1 = 0, last_channel_2 = 0, last_channel_3 = 0;
volatile uint32_t last_channel_4 = 0, last_channel_5 = 0, last_channel_6 = 0;
volatile uint32_t timer_1, timer_2, timer_3, timer_4, timer_5, timer_6;
volatile int ReceiverValue[6]; // Channels 1–6

// Receiver input pins
const int channel_1_pin = 34; // Roll
const int channel_2_pin = 35; // Pitch
const int channel_3_pin = 32; // Throttle
const int channel_4_pin = 33; // Yaw
const int channel_5_pin = 25; // Aux1 (Arm)
const int channel_6_pin = 26; // Aux2

// ----- PID variables ----- //
volatile float PtermRoll, ItermRoll, DtermRoll, PIDOutputRoll;
volatile float PtermPitch, ItermPitch, DtermPitch, PIDOutputPitch;
volatile float PtermYaw, ItermYaw, DtermYaw, PIDOutputYaw;  

int ThrottleIdle = 1170;
int ThrottleCutOff = 1000;

volatile float DesiredRateRoll, DesiredRatePitch, DesiredRateYaw;
volatile float ErrorRateRoll, ErrorRatePitch, ErrorRateYaw;
volatile float InputRoll, InputThrottle, InputPitch, InputYaw;
volatile float PrevErrorRateRoll, PrevErrorRatePitch, PrevErrorRateYaw;
volatile float PrevItermRateRoll, PrevItermRatePitch, PrevItermRateYaw;
volatile float PIDReturn[] = {0, 0, 0};

volatile float AccX, AccY, AccZ;
volatile float AngleRoll, AnglePitch;
volatile float DesiredAngleRoll, DesiredAnglePitch;
volatile float ErrorAngleRoll, ErrorAnglePitch;
volatile float PrevErrorAngleRoll, PrevErrorAnglePitch;
volatile float PrevItermAngleRoll, PrevItermAnglePitch;

float complementaryAngleRoll = 0.0f;
float complementaryAnglePitch = 0.0f;

volatile float MotorInput1, MotorInput2, MotorInput3, MotorInput4;

// ---------- Receiver Interrupt Handler ---------- //
void channelInterruptHandler() {
  current_time = micros();

  // Channel 1 (Roll)
  if (digitalRead(channel_1_pin)) {
    if (!last_channel_1) { last_channel_1 = 1; timer_1 = current_time; }
  } else if (last_channel_1) {
    last_channel_1 = 0; ReceiverValue[0] = current_time - timer_1;
  }

  // Channel 2 (Pitch)
  if (digitalRead(channel_2_pin)) {
    if (!last_channel_2) { last_channel_2 = 1; timer_2 = current_time; }
  } else if (last_channel_2) {
    last_channel_2 = 0; ReceiverValue[1] = current_time - timer_2;
  }

  // Channel 3 (Throttle)
  if (digitalRead(channel_3_pin)) {
    if (!last_channel_3) { last_channel_3 = 1; timer_3 = current_time; }
  } else if (last_channel_3) {
    last_channel_3 = 0; ReceiverValue[2] = current_time - timer_3;
  }

  // Channel 4 (Yaw)
  if (digitalRead(channel_4_pin)) {
    if (!last_channel_4) { last_channel_4 = 1; timer_4 = current_time; }
  } else if (last_channel_4) {
    last_channel_4 = 0; ReceiverValue[3] = current_time - timer_4;
  }

  // Channel 5 (Aux1)
  if (digitalRead(channel_5_pin)) {
    if (!last_channel_5) { last_channel_5 = 1; timer_5 = current_time; }
  } else if (last_channel_5) {
    last_channel_5 = 0; ReceiverValue[4] = current_time - timer_5;
  }

  // Channel 6 (Aux2)
  if (digitalRead(channel_6_pin)) {
    if (!last_channel_6) { last_channel_6 = 1; timer_6 = current_time; }
  } else if (last_channel_6) {
    last_channel_6 = 0; ReceiverValue[5] = current_time - timer_6;
  }
}

// ---------- IMU Data Acquisition ---------- //
void gyro_signals(void) {
  Wire.beginTransmission(0x68);
  Wire.write(0x1A); Wire.write(0x03); Wire.endTransmission();
  Wire.beginTransmission(0x68);
  Wire.write(0x1C); Wire.write(0x10); Wire.endTransmission();

  // --- Read Accelerometer --- //
  Wire.beginTransmission(0x68);
  Wire.write(0x3B); Wire.endTransmission();
  Wire.requestFrom(0x68, 6);
  int16_t AccXLSB = Wire.read() << 8 | Wire.read();
  int16_t AccYLSB = Wire.read() << 8 | Wire.read();
  int16_t AccZLSB = Wire.read() << 8 | Wire.read();

  // --- Read Gyroscope --- //
  Wire.beginTransmission(0x68);
  Wire.write(0x1B); Wire.write(0x08); Wire.endTransmission();
  Wire.beginTransmission(0x68);
  Wire.write(0x43); Wire.endTransmission();
  Wire.requestFrom(0x68, 6);
  int16_t GyroX = Wire.read() << 8 | Wire.read();
  int16_t GyroY = Wire.read() << 8 | Wire.read();
  int16_t GyroZ = Wire.read() << 8 | Wire.read();

  // Convert to engineering units
  RateRoll = (float)GyroX / 65.5;
  RatePitch = (float)GyroY / 65.5;
  RateYaw = (float)GyroZ / 65.5;
  AccX = (float)AccXLSB / 4096;
  AccY = (float)AccYLSB / 4096;
  AccZ = (float)AccZLSB / 4096;

  // Compute angles from accelerometer
  AngleRoll = atan(AccY / sqrt(AccX * AccX + AccZ * AccZ)) * 57.29;
  AnglePitch = -atan(AccX / sqrt(AccY * AccY + AccZ * AccZ)) * 57.29;
}

// ---------- PID Equation ---------- //
void pid_equation(float Error, float P, float I, float D, float PrevError, float PrevIterm) {
  float Pterm = P * Error;
  float Iterm = PrevIterm + (I * (Error + PrevError) * (t / 2));
  Iterm = constrain(Iterm, -400, 400);
  float Dterm = D * ((Error - PrevError) / t);
  float PIDOutput = constrain(Pterm + Iterm + Dterm, -400, 400);

  PIDReturn[0] = PIDOutput;
  PIDReturn[1] = Error;
  PIDReturn[2] = Iterm;
}

// ---------- Setup ---------- //
void setup(void) {
  Serial.begin(115200);

  // LED Blink (Boot Indicator)
  int led_time = 100;
  pinMode(15, OUTPUT);
  for (int i = 0; i < 8; i++) {
    digitalWrite(15, HIGH);
    delay(led_time);
    digitalWrite(15, LOW);
    delay(led_time);
  }
  
  // Receiver setup
  pinMode(channel_1_pin, INPUT_PULLUP);
  pinMode(channel_2_pin, INPUT_PULLUP);
  pinMode(channel_3_pin, INPUT_PULLUP);
  pinMode(channel_4_pin, INPUT_PULLUP);
  pinMode(channel_5_pin, INPUT_PULLUP);
  pinMode(channel_6_pin, INPUT_PULLUP);

  attachInterrupt(digitalPinToInterrupt(channel_1_pin), channelInterruptHandler, CHANGE);
  attachInterrupt(digitalPinToInterrupt(channel_2_pin), channelInterruptHandler, CHANGE);
  attachInterrupt(digitalPinToInterrupt(channel_3_pin), channelInterruptHandler, CHANGE);
  attachInterrupt(digitalPinToInterrupt(channel_4_pin), channelInterruptHandler, CHANGE);
  attachInterrupt(digitalPinToInterrupt(channel_5_pin), channelInterruptHandler, CHANGE);
  attachInterrupt(digitalPinToInterrupt(channel_6_pin), channelInterruptHandler, CHANGE);
  delay(100);

  // IMU initialization
  Wire.setClock(400000);
  Wire.begin();
  delay(250);
  Wire.beginTransmission(0x68);
  Wire.write(0x6B); Wire.write(0x00);
  Wire.endTransmission();

  // ESC setup
  ESP32PWM::allocateTimer(0);
  ESP32PWM::allocateTimer(1);
  ESP32PWM::allocateTimer(2);
  ESP32PWM::allocateTimer(3);

  delay(1000);  // Wait before attaching first motor

  // Attach and configure each motor with proper ESC frequency
  mot1.attach(mot1_pin, 1000, 2000);
  delay(1000);
  mot1.setPeriodHertz(ESCfreq);
  delay(100);

  mot2.attach(mot2_pin, 1000, 2000);
  delay(1000);
  mot2.setPeriodHertz(ESCfreq);
  delay(100);

  mot3.attach(mot3_pin, 1000, 2000);
  delay(1000);
  mot3.setPeriodHertz(ESCfreq);
  delay(100);

  mot4.attach(mot4_pin, 1000, 2000);
  delay(1000);
  mot4.setPeriodHertz(ESCfreq);
  delay(100);

  mot1.writeMicroseconds(1000);
  mot2.writeMicroseconds(1000);
  mot3.writeMicroseconds(1000);
  mot4.writeMicroseconds(1000);
  delay(500);

  // LED Blink (Motor Attached Indicator)
  pinMode(15, OUTPUT);
  for (int i = 0; i < 3; i++) {
    digitalWrite(15, HIGH);
    delay(led_time);
    digitalWrite(15, LOW);
    delay(led_time);
  }
  digitalWrite(15, LOW);
  delay(1000);
  digitalWrite(15, HIGH);

  // IMU calibration offsets (from IMU_Calibration.ino)

  /* Old values
  RateCalibrationRoll=-1.58;
  RateCalibrationPitch=1.68;
  RateCalibrationYaw=-0.05;
  AccXCalibration=0.10;
  AccYCalibration=0.01;
  AccZCalibration=0.03;
  */
  RateCalibrationRoll = -1.58;
  RateCalibrationPitch = 1.71;
  RateCalibrationYaw = -0.11;
  AccXCalibration = 0.04;
  AccYCalibration = -0.02;
  AccZCalibration = 0.03;

  LoopTimer = micros();
}

// ---------- Main Loop ---------- //
void loop(void) {
  // --- Read IMU data --- //
  Wire.beginTransmission(0x68);
  Wire.write(0x1A); Wire.write(0x05);
  Wire.endTransmission();

  Wire.beginTransmission(0x68);
  Wire.write(0x1C); Wire.write(0x10);
  Wire.endTransmission();

  Wire.beginTransmission(0x68);
  Wire.write(0x3B);
  Wire.endTransmission();
  
  Wire.requestFrom(0x68, 6);
  int16_t AccXLSB = Wire.read() << 8 | Wire.read();
  int16_t AccYLSB = Wire.read() << 8 | Wire.read();
  int16_t AccZLSB = Wire.read() << 8 | Wire.read();
  Wire.beginTransmission(0x68);
  Wire.write(0x1B); 
  Wire.write(0x8);
  Wire.endTransmission();  

  Wire.beginTransmission(0x68);
  Wire.write(0x1B); Wire.write(0x8);
  Wire.endTransmission();

  Wire.beginTransmission(0x68);
  Wire.write(0x43); 
  Wire.endTransmission();
  
  Wire.requestFrom(0x68, 6);
  int16_t GyroX = Wire.read() << 8 | Wire.read();
  int16_t GyroY = Wire.read() << 8 | Wire.read();
  int16_t GyroZ = Wire.read() << 8 | Wire.read();

  RateRoll = (float)GyroX / 65.5 - RateCalibrationRoll;
  RatePitch = (float)GyroY / 65.5 - RateCalibrationPitch;
  RateYaw = (float)GyroZ / 65.5 - RateCalibrationYaw;

  AccX = (float)AccXLSB / 4096 - AccXCalibration;
  AccY = (float)AccYLSB / 4096 - AccYCalibration;
  AccZ = (float)AccZLSB / 4096 - AccZCalibration;

  AngleRoll = atan(AccY / sqrt(AccX * AccX + AccZ * AccZ)) * 57.29;
  AnglePitch = -atan(AccX / sqrt(AccY * AccY + AccZ * AccZ)) * 57.29;

  // --- Complementary filter --- //
  complementaryAngleRoll = 0.991 * (complementaryAngleRoll + RateRoll * t) + 0.009 * AngleRoll;
  complementaryAnglePitch = 0.991 * (complementaryAnglePitch + RatePitch * t) + 0.009 * AnglePitch;

  // Clamp roll/pitch angles to ±20°
  complementaryAngleRoll = constrain(complementaryAngleRoll, -20, 20);
  complementaryAnglePitch = constrain(complementaryAnglePitch, -20, 20);

  // --- Desired values from receiver --- //
  DesiredAngleRoll = 0.1 * (ReceiverValue[0] - 1500);
  DesiredAnglePitch = 0.1 * (ReceiverValue[1] - 1500);
  InputThrottle = ReceiverValue[2];
  DesiredRateYaw = 0.15 * (ReceiverValue[3] - 1500);

  // ----- Nested PID: Angle → Rate → Motor control ----- //
  // Angle → Rate (Roll)
  ErrorAngleRoll = DesiredAngleRoll - complementaryAngleRoll;
  PtermRoll = PAngleRoll * ErrorAngleRoll;
  ItermRoll = PrevItermAngleRoll + (IAngleRoll * (ErrorAngleRoll + PrevErrorAngleRoll) * (t / 2));
  ItermRoll = constrain(ItermRoll, -400, 400);
  DtermRoll = DAngleRoll * ((ErrorAngleRoll - PrevErrorAngleRoll) / t);
  PIDOutputRoll = constrain(PtermRoll + ItermRoll + DtermRoll, -400, 400);
  DesiredRateRoll = PIDOutputRoll;
  PrevErrorAngleRoll = ErrorAngleRoll;
  PrevItermAngleRoll = ItermRoll;

  // Angle → Rate (Pitch)
  ErrorAnglePitch = DesiredAnglePitch - complementaryAnglePitch;
  PtermPitch = PAnglePitch * ErrorAnglePitch;
  ItermPitch = PrevItermAnglePitch + (IAnglePitch * (ErrorAnglePitch + PrevErrorAnglePitch) * (t / 2));
  ItermPitch = constrain(ItermPitch, -400, 400);
  DtermPitch = DAnglePitch * ((ErrorAnglePitch - PrevErrorAnglePitch) / t);
  PIDOutputPitch = constrain(PtermPitch + ItermPitch + DtermPitch, -400, 400);
  DesiredRatePitch = PIDOutputPitch;
  PrevErrorAnglePitch = ErrorAnglePitch;
  PrevItermAnglePitch = ItermPitch;

  // --- Rate PID for Roll, Pitch, Yaw --- //
  ErrorRateRoll = DesiredRateRoll - RateRoll;
  ErrorRatePitch = DesiredRatePitch - RatePitch;
  ErrorRateYaw = DesiredRateYaw - RateYaw;

  // Roll Rate PID
  PtermRoll = PRateRoll * ErrorRateRoll;
  ItermRoll = PrevItermRateRoll + (IRateRoll * (ErrorRateRoll + PrevErrorRateRoll) * (t / 2));
  ItermRoll = constrain(ItermRoll, -400, 400);
  DtermRoll = DRateRoll * ((ErrorRateRoll - PrevErrorRateRoll) / t);
  PIDOutputRoll = constrain(PtermRoll + ItermRoll + DtermRoll, -400, 400);
  InputRoll = PIDOutputRoll;
  PrevErrorRateRoll = ErrorRateRoll;
  PrevItermRateRoll = ItermRoll;

  // Pitch Rate PID
  PtermPitch = PRatePitch * ErrorRatePitch;
  ItermPitch = PrevItermRatePitch + (IRatePitch * (ErrorRatePitch + PrevErrorRatePitch) * (t / 2));
  ItermPitch = constrain(ItermPitch, -400, 400);
  DtermPitch = DRatePitch * ((ErrorRatePitch - PrevErrorRatePitch) / t);
  PIDOutputPitch = constrain(PtermPitch + ItermPitch + DtermPitch, -400, 400);
  InputPitch = PIDOutputPitch;
  PrevErrorRatePitch = ErrorRatePitch;
  PrevItermRatePitch = ItermPitch;

  // Yaw Rate PID
  PtermYaw = PRateYaw * ErrorRateYaw;
  ItermYaw = PrevItermRateYaw + (IRateYaw * (ErrorRateYaw + PrevErrorRateYaw) * (t / 2));
  ItermYaw = constrain(ItermYaw, -400, 400);
  DtermYaw = DRateYaw * ((ErrorRateYaw - PrevErrorRateYaw) / t);
  PIDOutputYaw = constrain(PtermYaw + ItermYaw + DtermYaw, -400, 400);
  InputYaw = PIDOutputYaw;
  PrevErrorRateYaw = ErrorRateYaw;
  PrevItermRateYaw = ItermYaw;

  // ----- Motor Mixing (X configuration) ----- //
  InputThrottle = constrain(InputThrottle, 1000, 1800);

  MotorInput1 = (InputThrottle - InputRoll - InputPitch - InputYaw); //Front Right - (CCW)
  MotorInput2 = (InputThrottle - InputRoll + InputPitch + InputYaw); //Rear Right - (CW)
  MotorInput3 = (InputThrottle + InputRoll + InputPitch - InputYaw); //Rear Left  - (CCW)
  MotorInput4 = (InputThrottle + InputRoll - InputPitch + InputYaw); //Front Left - (CW)

  // Clamp motor outputs to ESC range
  MotorInput1 = constrain(MotorInput1, ThrottleIdle, 1999);
  MotorInput2 = constrain(MotorInput2, ThrottleIdle, 1999);
  MotorInput3 = constrain(MotorInput3, ThrottleIdle, 1999);
  MotorInput4 = constrain(MotorInput4, ThrottleIdle, 1999);

  // ----- Safety: Disarm with AUX1 switch or throttle ----- //
  if (ReceiverValue[2] < 1030 || ReceiverValue[4] < 1500) {  // Throttle low OR AUX1 low
    MotorInput1 = ThrottleCutOff;
    MotorInput2 = ThrottleCutOff;
    MotorInput3 = ThrottleCutOff;
    MotorInput4 = ThrottleCutOff;

    // Reset PID errors and integrals
    PrevErrorRateRoll = 0; PrevErrorRatePitch = 0; PrevErrorRateYaw = 0;
    PrevItermRateRoll = 0; PrevItermRatePitch = 0; PrevItermRateYaw = 0;
    PrevErrorAngleRoll = 0; PrevErrorAnglePitch = 0;
    PrevItermAngleRoll = 0; PrevItermAnglePitch = 0;
  }

  // ----- Send outputs to motors ----- //
  mot1.writeMicroseconds(MotorInput1);
  mot2.writeMicroseconds(MotorInput2);
  mot3.writeMicroseconds(MotorInput3);
  mot4.writeMicroseconds(MotorInput4);

  // ----- Maintain fixed loop timing ----- //
  while (micros() - LoopTimer < (t * 1000000)) {
    // wait
  }
  LoopTimer = micros();
}

// PID Values =>
// PAngleRoll / PAnglePitch -> Strength of self-leveling when drone leans sideways (roll) or when nose dips or rises (pitch)
//      ↑ Increase: Levels faster but may oscillate
//      ↓ Decrease: Slower leveling, feels loose
// IAngleRoll / IAnglePitch -> Fixes slow roll / pitch drift over time
//      ↑ Increase: Better drift correction, may cause slow oscillation
//      ↓ Decrease: May drift or not hold level
// DAngleRoll / DAnglePitch -> Reduces wobble when correcting roll / pitch
//      ↑ Increase: Smoother motion, less overshoot, can cause motor jitter
//      ↓ Decrease: More wobble or bounce when leveling

// PRateRoll / PRatePitch -> How sharply it rolls/pitches on stick input
//      ↑ Increase: Faster, more responsive, may oscillate
//      ↓ Decrease: Slower, less responsive
// IRateRoll / IRatePitch -> Keeps constant roll/pitch rate, resists bias
//      ↑ Increase: Better rate hold, may cause slow oscillation
//      ↓ Decrease: Uneven or drifting rate
// DRateRoll / DRatePitch -> Smooths rapid roll/pitch movements
//      ↑ Increase: Smoother stops, reduces overshoot, may add noise
//      ↓ Decrease: Bouncy or overshooting stops

// PRateYaw -> How fast it rotates on yaw stick input
//      ↑ Increase: Faster yaw response, may oscillate
//      ↓ Decrease: Sluggish yaw
// IRateYaw -> Keeps heading steady, resists drift
//      ↑ Increase: Better heading hold, may cause slow oscillation
//      ↓ Decrease: Yaw drift over time
// DRateYaw -> Prevents overshoot in turns
//      ↑ Increase: Smoother yaw stop, can add delay or noise
//      ↓ Decrease: Overshoots or jerky yaw stops

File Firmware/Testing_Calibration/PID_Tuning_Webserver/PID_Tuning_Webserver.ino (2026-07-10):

// ============================================================================
//                                LIBRARIES
// ============================================================================
#include <WiFi.h>
#include <AsyncTCP.h>
#include <ESPAsyncWebServer.h>
#include <SPIFFS.h>
#include <Wire.h>
#include <ESP32Servo.h>

// ============================================================================
//                              WIFI CREDENTIALS
// ============================================================================
const char* ssid     = "WiFi Name";
const char* password = "Password";

// ============================================================================
//                         GLOBAL PID CONSTANTS (INITIAL)
// ============================================================================
float PRateRoll = 1.25;
float IRateRoll = 0.021;
float DRateRoll = 0.012;

float PAngleRoll = 3.8;
float IAngleRoll = 0.021;
float DAngleRoll = 0.032;

float PRateYaw = 3;
float IRateYaw = 1.4;
float DRateYaw = 0.015;

float ESCfreq = 500;

float PRatePitch  = PRateRoll;
float IRatePitch  = IRateRoll;
float DRatePitch  = DRateRoll;
float PAnglePitch = PAngleRoll;
float IAnglePitch = IAngleRoll;
float DAnglePitch = DAngleRoll;

float t = 0.010; // Loop cycle time
uint32_t LoopTimer;

// ============================================================================
//                          IMU + SENSOR GLOBAL VARIABLES
// ============================================================================
volatile float RateRoll, RatePitch, RateYaw;
volatile float RateCalibrationRoll, RateCalibrationPitch, RateCalibrationYaw;
volatile float AccXCalibration, AccYCalibration, AccZCalibration;

volatile float AccX, AccY, AccZ;
volatile float AngleRoll, AnglePitch;

float complementaryAngleRoll = 0.0f;
float complementaryAnglePitch = 0.0f;

// ============================================================================
//                           MOTOR CONFIGURATION
// ============================================================================
Servo mot1, mot2, mot3, mot4;
const int mot1_pin = 13;
const int mot2_pin = 12;
const int mot3_pin = 14;
const int mot4_pin = 27;

int ThrottleIdle   = 1170;
int ThrottleCutOff = 1000;

// ============================================================================
//                           RECEIVER CONFIGURATION
// ============================================================================
volatile uint32_t current_time;

volatile uint32_t last_channel_1 = 0;
volatile uint32_t last_channel_2 = 0;
volatile uint32_t last_channel_3 = 0;
volatile uint32_t last_channel_4 = 0;
volatile uint32_t last_channel_5 = 0;
volatile uint32_t last_channel_6 = 0;

volatile uint32_t timer_1, timer_2, timer_3, timer_4, timer_5, timer_6;
volatile int ReceiverValue[6];

const int channel_1_pin = 34;
const int channel_2_pin = 35;
const int channel_3_pin = 32;
const int channel_4_pin = 33;
const int channel_5_pin = 25;
const int channel_6_pin = 26;

// ============================================================================
//                            PID WORKING VARIABLES
// ============================================================================
volatile float PtermRoll,  ItermRoll,  DtermRoll,  PIDOutputRoll;
volatile float PtermPitch, ItermPitch, DtermPitch, PIDOutputPitch;
volatile float PtermYaw,   ItermYaw,   DtermYaw,   PIDOutputYaw;

volatile float DesiredAngleRoll, DesiredAnglePitch;
volatile float DesiredRateRoll, DesiredRatePitch, DesiredRateYaw;

volatile float ErrorAngleRoll, ErrorAnglePitch;
volatile float ErrorRateRoll,  ErrorRatePitch,  ErrorRateYaw;

volatile float PrevErrorAngleRoll, PrevErrorAnglePitch;
volatile float PrevErrorRateRoll, PrevErrorRatePitch, PrevErrorRateYaw;

volatile float PrevItermAngleRoll, PrevItermAnglePitch;
volatile float PrevItermRateRoll,  PrevItermRatePitch,  PrevItermRateYaw;

volatile float InputRoll, InputPitch, InputYaw, InputThrottle;

volatile float MotorInput1, MotorInput2, MotorInput3, MotorInput4;

volatile float PIDReturn[] = {0, 0, 0};

// ============================================================================
//                         WIFI + PID TUNING SERVER
// ============================================================================
AsyncWebServer server(80);

const char* PARAM_P_GAIN = "pGain";
const char* PARAM_I_GAIN = "iGain";
const char* PARAM_D_GAIN = "dGain";

const char* PARAM_P_A_GAIN = "pAGain";
const char* PARAM_I_A_GAIN = "iAGain";
const char* PARAM_D_A_GAIN = "dAGain";

const char* PARAM_P_YAW = "pYaw";
const char* PARAM_I_YAW = "iYaw";
const char* PARAM_D_YAW = "dYaw";

const char* PARAM_TIME_CYCLE = "tc";

// ============================================================================
//                                HTML PAGE
// ============================================================================
const char index_html[] PROGMEM = R"rawliteral(
<!DOCTYPE HTML>
<html>
<head>
  <title>ESP32 PID Tuning</title>
  <meta name="viewport" content="width=device-width, initial-scale=1">
  <style>
    body {
      font-family: Arial, sans-serif;
      background-color: #f2f4f8;
      margin: 0;
      padding: 20px;
    }

    h2 {
      text-align: center;
      color: #333;
    }

    .container {
      max-width: 600px;
      margin: auto;
      background: #ffffff;
      padding: 20px;
      border-radius: 8px;
      box-shadow: 0 4px 10px rgba(0,0,0,0.08);
    }

    .section {
      margin-bottom: 25px;
    }

    .section h3 {
      margin-bottom: 10px;
      color: #444;
      border-bottom: 1px solid #ddd;
      padding-bottom: 5px;
    }

    .row {
      display: flex;
      align-items: center;
      margin-bottom: 10px;
    }

    .row label {
      flex: 1;
      font-size: 14px;
    }

    .row input {
      flex: 1;
      padding: 6px;
      margin-right: 8px;
      border-radius: 4px;
      border: 1px solid #ccc;
    }

    .row button {
      padding: 6px 12px;
      border-radius: 4px;
      border: none;
      background-color: #007bff;
      color: white;
      cursor: pointer;
    }

    .row button:hover {
      background-color: #0056b3;
    }

    .current {
      font-size: 12px;
      color: #777;
      margin-left: 5px;
    }

  </style>

  <script>
    function submitMessage() {
      alert("Value saved!");
      setTimeout(() => { location.reload(); }, 300);
    }
  </script>
</head>
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
